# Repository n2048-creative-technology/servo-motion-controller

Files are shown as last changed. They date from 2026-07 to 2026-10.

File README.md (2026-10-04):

# Servo Motion Controller (XIAO ESP32C3 / ESP32S3)

A self-contained servo motion sequencer for a Seeed XIAO ESP32C3 **or**
ESP32S3, powered over USB-C. On boot it creates its own WiFi access point and
hosts a mobile-first web app (open the AP's IP in a phone browser, WLED-style)
for:

- Live manual aiming of a **pan/tilt head** — two servos, X (pan) on D10 and
  Y (tilt) on D3 — with a square XY trackpad whose extents follow each axis's
  own calibrated travel (270° out of the box, 180° if that's how you set that
  servo up).
- A relay output on pin **D7** for a light, switched by a toggle beside the
  trackpad.
- Parametric motion patterns — sine, square, triangle, sawtooth, trapezoid —
  each with adjustable period/amplitude/offset (and duty or rise/hold/fall
  ratios where relevant), looped continuously. **Each axis runs its own
  shape**, so the head can sweep in pan while nodding slowly in tilt.
- A **random** pattern: new target angles picked inside that axis's calibrated
  range at randomly-drawn intervals between two limits you set. Every move is
  speed-limited and eased in/out rather than jumped, so the servo tracks it
  smoothly instead of slamming from one position to the next. Set both axes to
  random and they share one schedule — the head looks at a whole new point
  each interval instead of twitching one axis at a time.
- Recording a manual performance (drag the trackpad) as a timestamped
  sequence, then saving and looping it back — both axes and the relay's state
  are captured and replayed together. Up to 6min40s per recording.
- An **autostart** setting: on every power-up/reset, the configured pattern
  or saved sequence starts looping automatically with no user interaction,
  because it's applied *before* WiFi/the web server come up.

## Hardware

Two supported boards, one firmware — pick the matching PlatformIO
environment (`seeed_xiao_esp32c3` or `seeed_xiao_esp32s3`) when building/flashing.

| | XIAO ESP32C3 | XIAO ESP32S3 |
|---|---|---|
| Power | USB-C (5V from host/charger) | USB-C (5V from host/charger) |
| Servo X (pan) | **pin D10 (GPIO10)** → servo signal wire | **pin D10 (GPIO9)** → servo signal wire |
| Servo Y (tilt) | **pin D3 (GPIO5)** → servo signal wire | **pin D3 (GPIO4)** → servo signal wire |
| Relay / light | **pin D7 (GPIO20)** → relay module IN | **pin D7 (GPIO44)** → relay module IN |
| Flash / RAM | 4MB / ~400KB SRAM | 8MB / ~512KB SRAM |

Both boards use the **same silkscreen-labeled pins** for all three outputs
— D10 (pan), D3 (tilt), D7 (relay) — so no wiring changes are needed when
switching boards, but note each is a *different underlying GPIO number* on
each chip (`SERVO_X_PIN` / `SERVO_Y_PIN` / `RELAY_PIN` in
`firmware/include/Config.h` are selected per-board via `ARDUINO_XIAO_ESP32S3`,
already handled for you).

| | |
|---|---|
| Servo power | **Do not power the servos from the XIAO's 3V3/5V pin.** Two servos that can move at once roughly double the peak draw; use a separate 5–6V supply sized for both, with its ground tied to the XIAO's GND. The relay module's coil side runs off that same supply, not the XIAO's 3V3. |
| Servo pulse range | Default 500–2500 µs, calibratable **per axis** in Settings (min/max pulse, min/max angle, center, invert) |

The default calibration assumes wide-range (~270°) servos, matching pulse
widths used in other projects in this workspace. Adjust min/max angle and
pulse width in the web UI's Settings tab to match each of your actual servos —
pan and tilt are calibrated separately, since a tilt servo usually has a
different mechanical range.

## Access point

- Default SSID: `ServoRig-XXXXXX` (last 3 MAC bytes, printed on the serial
  console at boot).
- Default password: `servo1234` (change it from Settings; leave it blank to
  run an open network — minimum 8 characters otherwise).
- Fixed AP IP: `192.168.4.1`. Visiting any other hostname while connected
  redirects there (best-effort captive portal — phone OS auto-popup
  detection isn't 100% reliable, so if it doesn't pop up, open
  `http://192.168.4.1/` manually).
- **There is no recovery WiFi network.** If you forget a custom AP password,
  the only way back in is `POST /api/settings/reset` — which you can't reach
  without a connection. In practice: flash a fresh build, or add a physical
  factory-reset trigger (e.g. a boot-time GPIO check) if you expect to need
  this in the field — not implemented here to keep scope minimal.
- Two arduino-esp32 gotchas that used to cause "correct password rejected"
  and "settings reset to factory defaults on every reflash" are worked
  around in `main.cpp`'s `setup()`: `WiFi.persistent(false)` stops a stale
  flash-cached AP config from fighting the one set at boot, and
  `WiFi.softAP()` is always called before `WiFi.softAPConfig()` (the reverse
  order silently drops the password even though `softAP()` reports success).
  Separately, AP SSID/password and Master/Node role/Node ID are stored under
  their own NVS key, independent of the versioned settings blob — so bumping
  `SETTINGS_VERSION` for an unrelated field (a new calibration option, a new
  pattern parameter) no longer wipes them back to factory defaults.

## Build & flash

Requires [PlatformIO](https://platformio.org/) (`pio` CLI).

**Pin the platform first**: `platform = espressif32` in `platformio.ini` is
unpinned, and the current release of it no longer compiles `NetworkLink.cpp`
(ESP-NOW callback signature change in arduino-esp32 3.x — see Known
limitations at the end). Use `platform = espressif32@6.10.0`, the version this
was developed and flashed with.

```bash
cd firmware
ENV=seeed_xiao_esp32c3   # or seeed_xiao_esp32s3
pio run -e $ENV              # compile firmware
pio run -e $ENV -t buildfs   # build the LittleFS web UI image

# with the board connected over USB-C:
pio run -e $ENV -t upload
pio run -e $ENV -t uploadfs
pio device monitor -e $ENV -b 115200
```

Both `firmware.bin` and the LittleFS image (`index.html`/`app.js`/`style.css`
in `firmware/data/`) must be flashed — `uploadfs` pushes the web UI, `upload`
pushes the firmware. Re-run `uploadfs` any time you edit files in `data/`.

**Native USB-CDC quirk on both XIAO boards**: `esptool`'s default
post-connect baud-rate change (and the RAM-stub handoff) failed consistently
over the native USB-CDC/JTAG port (`No serial data received` after "Stub
running..."). Fixed by pinning `upload_speed = 115200` and
`upload_flags = --no-stub` for both environments in `platformio.ini` (already
set) — `--no-stub` talks to the ROM bootloader directly instead of handing
off to a RAM stub, which is slower per-byte but reliable over this port. If
you flash from a different machine/OS and hit the same error, that's the
first thing to try; if your setup doesn't need it, it's harmless to leave in.

Verified end-to-end on real hardware, both boards: firmware and filesystem
flashed successfully to a connected XIAO ESP32C3 and a connected XIAO
ESP32S3, and each one's serial self-test log confirmed a clean boot —
settings loaded, both servos attached on the correct pins (GPIO10/GPIO5 on
the C3, GPIO9/GPIO4 on the S3 — silkscreen D10 and D3), the relay driven to
its off level on D7, LittleFS mounted, WiFi AP up
(`ServoRig-xxxxxx` @ `192.168.4.1`), web server started (~195KB free heap on
the C3, ~259KB on the S3, matching its larger SRAM). **Not verified**: the
web UI and API themselves, since this environment has no WiFi adapter to
join the AP and exercise `/api/*` or the WebSocket over the air — connect a
phone or laptop to the AP and walk through [docs/self-test.md](docs/self-test.md)'s
functional checklist (jog, pattern loop, record/save, autostart-after-reset)
to finish verification.

## Web app

Three tabs, reachable from the bottom nav:

- **Manual** — XY trackpad (live, ~25 Hz over WebSocket) with a Light toggle
  for the D7 relay beside it, + a pattern picker per axis with generated
  parameter fields and Start/Stop. The pad's extents and the pattern forms'
  angle fields both follow the per-axis calibration set in Settings. On a
  Master, two extra cards sit on top: **Target** (which Node(s) the controls
  drive) and **Play Sequence on Nodes** (make them loop a sequence saved on
  their own flash) — see *Multi-board Master/Node mode* below.

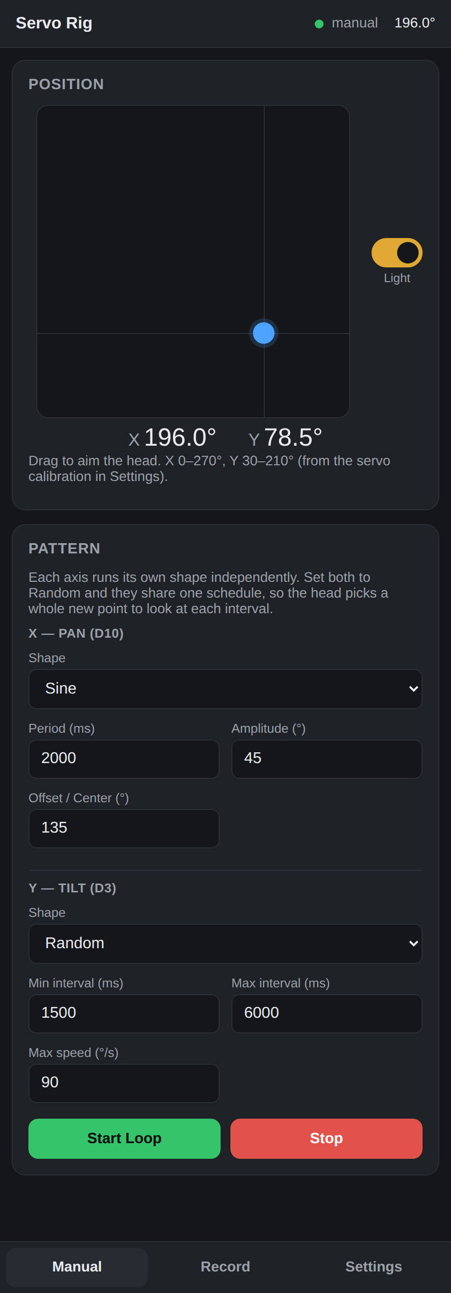
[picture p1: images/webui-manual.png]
Manual tab: XY trackpad with Light toggle, and a pattern shape per axis
  

- **Record** — start/stop recording (captures both servo axes *and* the
  relay's state at a fixed 20 Hz while you aim the head), live trace with one
  line per axis, **tap any saved recording to plot it** (with a playhead
  tracking it while it plays), save/discard,
  and play/stop the saved sequence on a loop. Playback drives the light from
  the recording just as it drives the servo. The trace plots both: the servo
  axes as two lines, and the light as a solid lane along the bottom (with a
  faint wash over the motion it happened during), so you can see at a glance
  which part of a take was lit. The same plot shows a *saved* recording when
  you tap its row in the list, downsampled by the board, with a thin white
  playhead following playback through it.

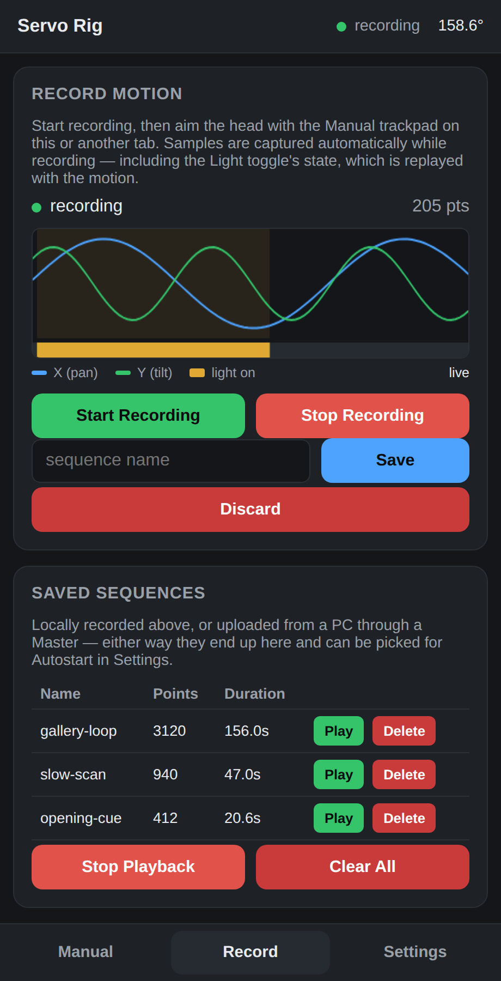
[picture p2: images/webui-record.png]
Record tab: live trace of both axes plus the light lane, and the saved-sequence list
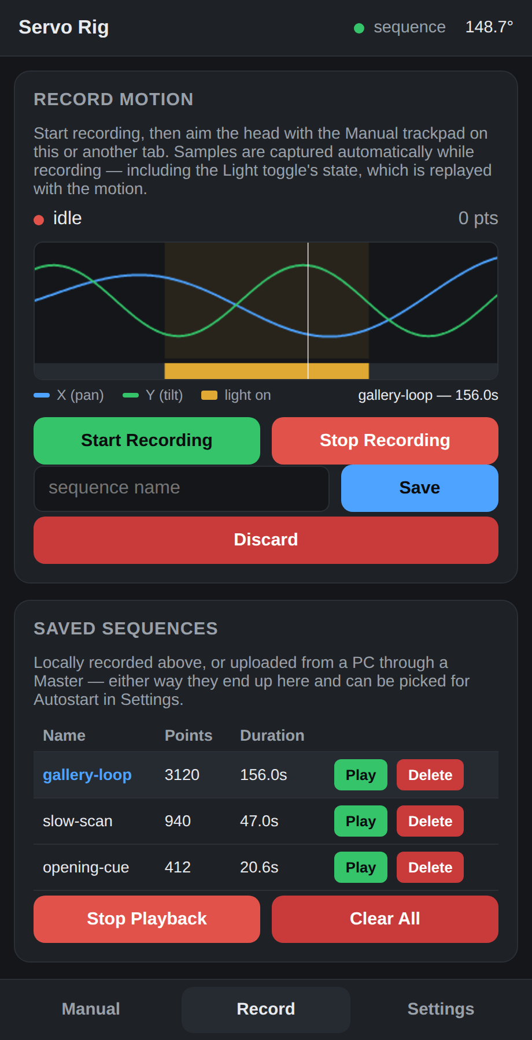
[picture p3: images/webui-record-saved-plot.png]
Record tab: a saved recording plotted with a playhead sweeping through it
   

  *Left: recording in progress — pan and tilt as two lines, the light as a
  lane along the bottom. Right: a saved recording tapped in the list, plotted
  with the white playhead tracking playback through it.*

- **Settings** — AP SSID/password, per-axis servo calibration (including
  **Invert direction**, for a servo mounted mirrored/reversed relative to its
  calibrated min/max angle), relay polarity (**Active low**, for the
  opto-isolated relay boards that switch closed on a low input), autostart
  enable/target (pattern or sequence) with its own parameter fields, and a
  factory-reset button.

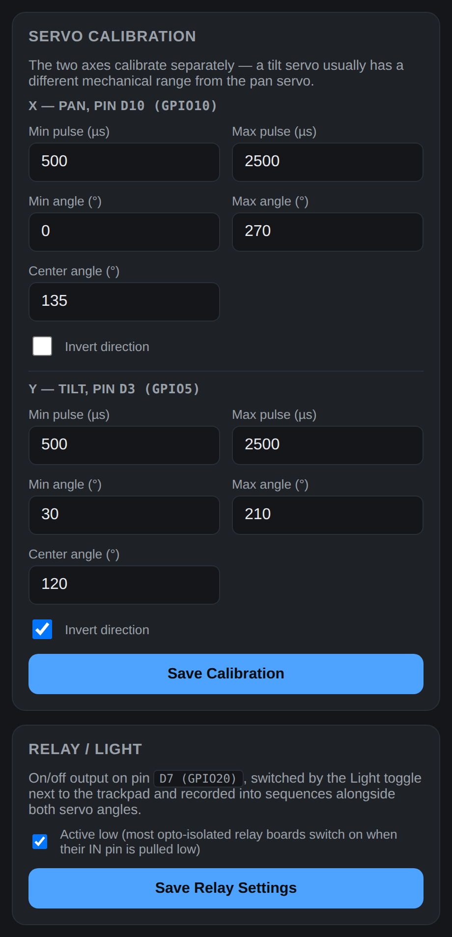
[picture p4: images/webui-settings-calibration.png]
Settings tab: per-axis servo calibration with invert checkboxes, and relay polarity
  

## REST / WebSocket API

See [docs/api.md](docs/api.md) for the full route table and payload shapes.
WebSocket `/ws` pushes `{"type":"status", mode, x, y, relay_on, ...}` at
~10 Hz and accepts `{"cmd":"jog","x":123.4,"y":90.0}` and
`{"cmd":"relay","on":true}` for low-latency manual control; on a Master it
also pushes `{"type":"play_result",...}` whenever a Node answers a play
request (`POST /api/network/play`). (`angle` is still
sent and accepted as a deprecated alias for `x`, so anything written against
the single-servo API keeps working.)

## Multi-board Master/Node mode (v2)

Every board still runs the same firmware and, by default, is exactly the
self-contained pan/tilt-plus-light rig described above (**Standalone** mode).
On top of that, a board can be switched (Settings → Network) into:

Settings → Network, all three modes:

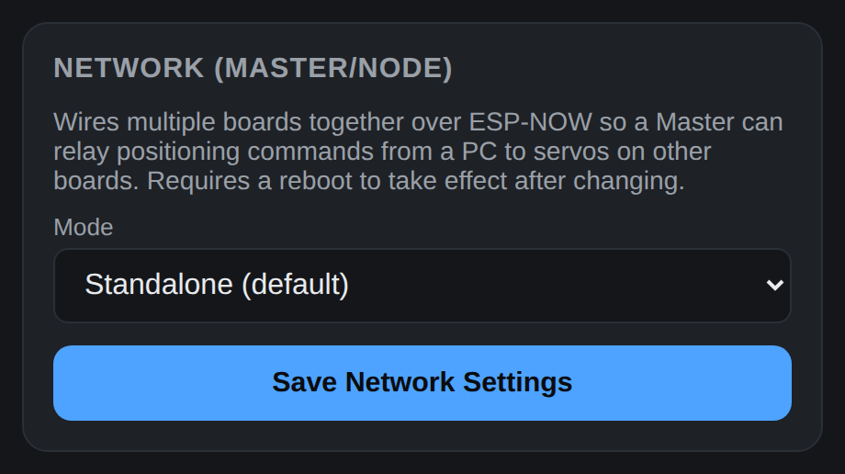
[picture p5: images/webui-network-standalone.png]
Network settings: Standalone mode
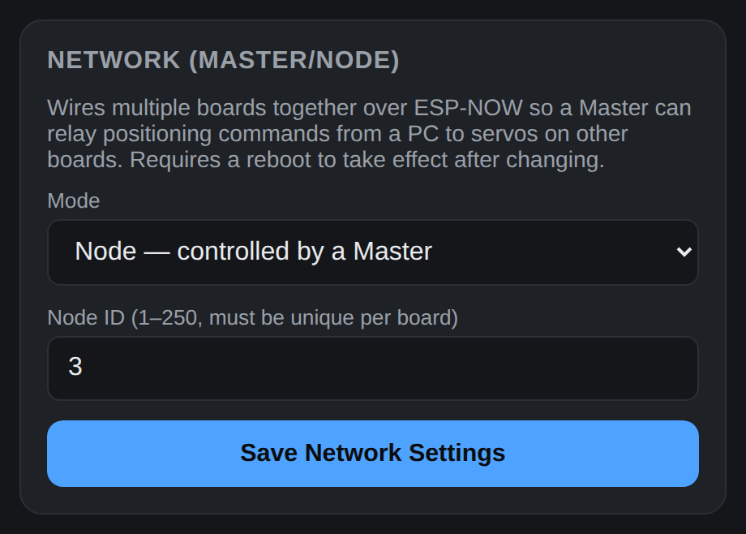
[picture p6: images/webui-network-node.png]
Network settings: Node mode with Node ID field
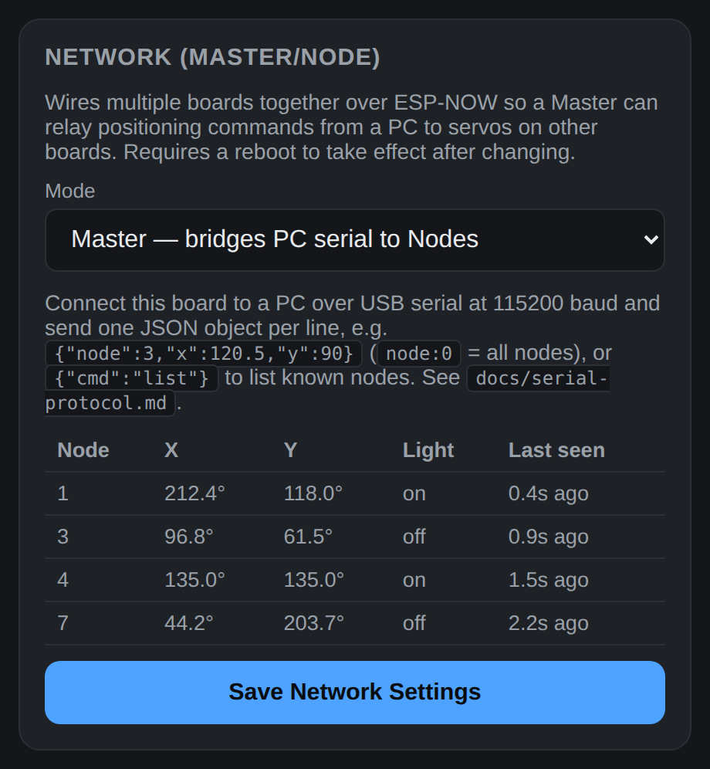
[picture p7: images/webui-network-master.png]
Network settings: Master mode with the known-nodes table showing each Node's pan, tilt and light
  

- **Node** — everything Standalone does, plus a **Node ID** (1–250) and an
  ESP-NOW listener: it accepts wireless positioning commands from a Master in
  addition to local jog/pattern/sequence control, and reports its status as
  `mode: "network"` while being driven that way. A local jog on the same
  board's web UI still takes over immediately (last command wins — there's no
  arbitration between the two sources).
- **Master** — a bridge, not a servo controller: connect it to a PC over
  USB-C and it relays newline-delimited JSON commands from that serial port
  to every Node in ESP-NOW range. See [docs/serial-protocol.md](docs/serial-protocol.md)
  for the wire format (`{"node":3,"x":120.5,"y":90.0}`, `{"cmd":"list"}`,
  etc.) and a `pyserial` example. A Master needs no servos attached.
  It can also tell Nodes to loop a sequence saved on their own flash
  (`{"cmd":"remote_play","node":3,"name":"dance1"}`, `node: 0` for all at
  once) and stop it again (`remote_stop`); the next ordinary move command
  takes a Node back to live control. Needs firmware 2.3.0+ on both ends.
  Both PC GUIs below have a **Play saved sequence on Node(s)** panel for this,
  and so does the Master's own web UI (2.4.0+, see next paragraph).

  A Master's **own web UI works too**: its Manual tab gets a "Target" card
  (Settings → Network → Master) listing known Nodes as checkboxes — select
  one, several, or check "All nodes" — and the existing trackpad / Light
  toggle / Pattern controls drive that selection over ESP-NOW instead of a
  local servo. Below it, **Play Sequence on Nodes** makes the selected
  Node(s) loop a sequence saved on their own flash (type the name — the
  Master's own saved names are suggested) and **Stop on Nodes** halts them;
  each Node's reply (playing / no such sequence / busy recording) is listed
  underneath. Handy
  for driving the rig by hand from a phone without any PC involved at all;
  the serial bridge above is for scripted/external control.

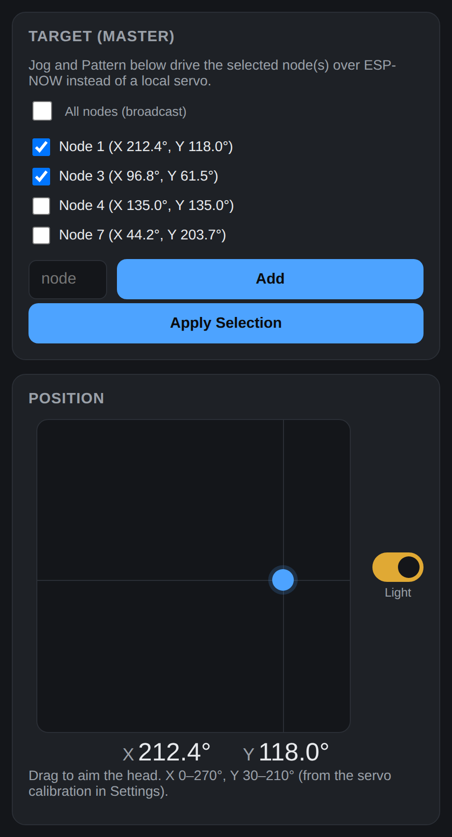
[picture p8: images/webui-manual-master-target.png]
Master's Manual tab: Target card listing known Nodes with their pan/tilt positions, above the trackpad
  

  For PC-driven control there's also [scripts-tools/master_gui.py](scripts-tools/master_gui.py),
  a small Tkinter app that connects to a Master's serial port, shows its known
  Nodes (pan, tilt, light state and age), and lets you aim a selection of them
  with an XY pad — light included — or broadcast to all, without writing any
  code:

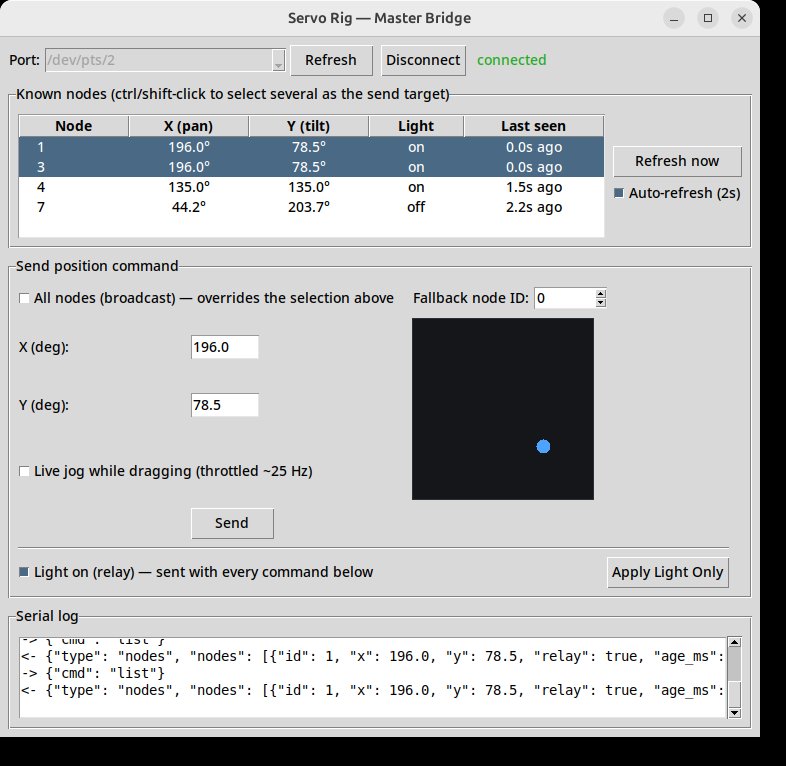
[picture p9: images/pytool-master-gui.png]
master_gui.py: known-nodes table with X/Y/Light columns, XY pad and light checkbox
  

  and [scripts-tools/joystick_master_gui.py](scripts-tools/joystick_master_gui.py),
  which links physical joysticks/gamepads to Nodes (with a "learn the axis"
  step that takes a whole stick as one pan/tilt pair, and buttons as a Node's
  light), streams live movement to them, and can record a performance to CSV
  (Node ID + pan + tilt + light per timestamp) for standalone replay without
  the controller — see [scripts-tools/README.md](scripts-tools/README.md).

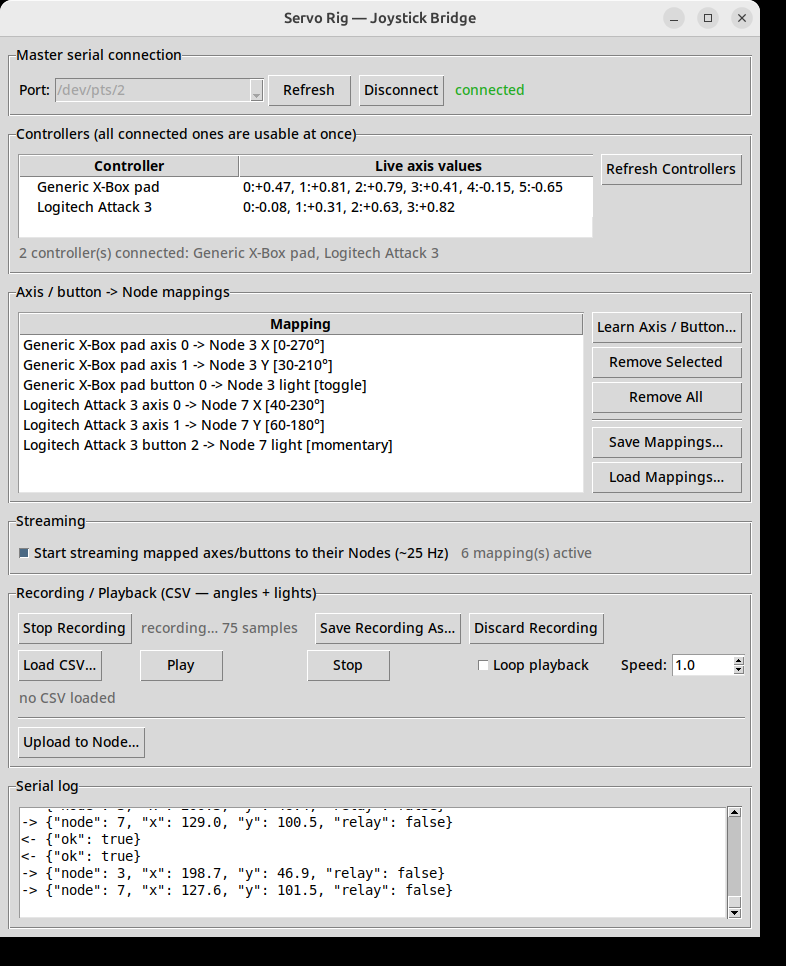
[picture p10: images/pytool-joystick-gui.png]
joystick_master_gui.py: two controllers detected, per-axis and per-button node mappings, streaming and recording
  

  **A performance doesn't have to stay tied to the PC.** `joystick_master_gui.py`'s
  **Upload to Node…** button takes a loaded CSV or a just-made recording,
  picks one Node ID present in it, and streams *only that Node's own column*
  through the Master to be saved on the Node's own flash under a name —
  other Nodes' data in the same recording is never sent to it. That Node's
  own Settings → Autostart can then pick any of its saved sequences (see the
  Record tab's list — locally recorded or uploaded, they show up the same
  way) to loop on every boot, completely standalone: no PC, no Master, no
  controller needed afterward. See
  [docs/serial-protocol.md](docs/serial-protocol.md)'s
  `remote_record_start`/`remote_record_stop` for the underlying protocol —
  it's implemented as a remotely-triggered recording, reusing the same
  RECORDING-mode capture path a Node's own web UI already uses.

How it works: Master and Nodes talk over **ESP-NOW** (direct ESP32-to-ESP32
radio, no router involved), broadcasting on the same fixed AP WiFi channel
every board already uses (`AP_WIFI_CHANNEL` in `firmware/include/Config.h`).
That's what makes it a drop-in addition to the existing self-contained-AP
design — no board has to join anyone else's network. The only setup step per
board is picking its mode and, for Nodes, a unique Node ID, from its own
Settings → Network tab; changes take effect after a reboot.

Known limitation: like the rest of this project's networking, there's no
encryption or pairing beyond the shared channel + Node ID — anyone else's
ESP-NOW traffic on the same channel with a colliding Node ID could also drive
a Node. Fine for a single installation's private RF environment; don't rely
on it where that's not true.

**Dropped packets self-heal.** A Node's radio/CPU is shared with whatever
else it's doing — e.g. a phone joining that same Node's AP to view its web
UI competes with ESP-NOW for airtime on the single RISC-V core. Rather than
a dropped command leaving a Node stuck, the Master re-sends the last angle
it sent to each target at least every 300ms even if unchanged, and each Node
independently re-applies its own last commanded angle to the servo at least
every 250ms — see `NET_CMD_RESEND_INTERVAL_MS`/`SERVO_REAPPLY_INTERVAL_MS` in
`firmware/include/Config.h`. Whichever command reached a Node *last* (local
jog, another app, a gamepad stream) always wins; if a gamepad moves faster
than packets can be delivered, intermediate positions may be skipped but the
Node reliably converges on the final position once movement stops.

That resend mechanism means more than one command for the same target is
often in flight, and a congested/degrading link (that same phone-on-the-AP
scenario) can deliver them **out of order** — without protection, a delayed
resend of an older angle arriving after a newer command would erratically
snap the servo backward. Every command now carries a per-boot session id
plus an increasing sequence number; a Node drops anything not newer than
what it already applied, so a late/stale packet is a no-op rather than a
step backward. This is the fix for the "servo moves erratically when the
network connection is flaky" symptom — see
[docs/serial-protocol.md](docs/serial-protocol.md) for the full picture.
Because the packet layout changed, **Master and every Node need matching
firmware** — a version mismatch makes them silently ignore each other
rather than misbehave.

## Storage

- Servo calibration, AP credentials, and autostart config live in NVS
  (`Preferences`, versioned blob — a magic/version mismatch falls back to
  factory defaults instead of crashing).
- Each recorded sequence lives in LittleFS at `/seq/<name>.bin` (12-byte
  header + up to 8000 points of `{t_ms, x*10, y*10, flags}`, i.e. up to
  6min40s at the 20 Hz capture rate — a board can hold several, named, picked
  for autostart or manual playback). It's only written on explicit **Save**,
  never per-sample, to avoid flash wear. A point is 12 bytes; when the Y axis
  was added the point count came down from 12000 so the fixed buffer stayed at
  the same 96KB rather than eating another 48KB of the C3's RAM. Sequences
  recorded by older firmware still load: their X and light tracks replay as
  before, and tilt is left alone rather than driven somewhere the recording
  never described.

## Known limitations / risks

- Single RISC-V core: the 50 Hz servo tick shares the core with
  AsyncWebServer/WebSocket event handling. Route handlers are kept
  non-blocking and JSON payloads small to avoid starving the tick.
- Captive-portal auto-popup varies by phone OS; the DNS catch-all + redirect
  is best-effort, `192.168.4.1` is the documented fallback.
- No STA/recovery network — see the access point section above.
- Flash is fairly full (72.3% of the app partition — 947,794 of 1,310,720
  bytes on the C3 as of v2.2.0) since `ESPAsyncWebServer` + `ArduinoJson` +
  `ESP32Servo` are meaningfully sized libraries on a 1.25MB app partition. If
  you add more features and hit the ceiling, look at a non-OTA partition
  table (`board_build.partitions`) to reclaim the unused second OTA app slot.
- **`platform = espressif32` is unpinned in `platformio.ini`, and the current
  release of it no longer builds this firmware.** arduino-esp32 3.x /
  ESP-IDF 5.x changed the ESP-NOW receive callback signature, so
  `NetworkLink.cpp`'s `esp_now_register_recv_cb(onRecvTrampoline)` fails to
  compile: `invalid conversion from 'void (*)(const uint8_t*, const uint8_t*,
  int)' to 'esp_now_recv_cb_t'` (the callback now takes a
  `const esp_now_recv_info*` first argument, carrying the sender MAC in
  `->src_addr`). This project was developed against **espressif32 6.10.0**,
  which is still installed here and builds cleanly. Until the trampoline is
  ported, pin it — `platform = espressif32@6.10.0` in `[env]` — or update the
  callback signature. Everything else in this repo (the web UI filesystem
  image included) builds on either.
- Master/Node mode is build-verified (`pio run` / `-t buildfs` both succeed)
  and boards on hand have been flashed and boot-confirmed over serial
  (settings v6, LittleFS OK, AP up), but the actual ESP-NOW link between a
  Master and a Node (a real serial or web-UI command moving a *remote*
  servo) hasn't been hands-on verified end-to-end from this environment —
  it has no WiFi adapter to join a board's AP and drive its web UI over the
  air. Set one board to Master / another to Node with a chosen Node ID and
  confirm it responds before relying on this in the field. AP SSID/password
  and Master/Node role/Node ID no longer reset on a `SETTINGS_VERSION` bump
  (they live under their own NVS key — see the Access point section above),
  so this no longer needs re-picking after an unrelated firmware update.
- The command-resend/reapply/ordering robustness mechanisms (see above) are
  build-verified and flashed to all 4 boards on hand, but reproducing the
  actual failure mode (a phone joined to a Node's AP while a gamepad drives
  it through the Master) needs real hardware, a real phone, and a real
  gamepad simultaneously, none of which this sandbox has all at once. Worth
  confirming in the field that a Node recovers on its own within
  ~300-550ms of the interference easing, without needing a reboot, and that
  it no longer snaps backward to a stale angle while doing so.
- Remote sequence upload (`remote_record_start`/`remote_record_stop`, and
  `joystick_master_gui.py`'s Upload to Node… button) is build-verified only —
  it bumped `NET_PACKET_VERSION` again (every board needs reflashing to stay
  in sync, same as the ordering fix above) and reuses well-exercised
  machinery (RECORDING mode, `resample_rows`), but the actual PC → Master →
  Node round trip, the on-Node save, and autostart picking it back up after
  a reboot haven't been exercised hands-on for the same no-WiFi-adapter
  reason as the rest of Master/Node mode. Worth a real end-to-end check:
  upload something, confirm it shows up in that Node's Settings → Autostart
  sequence picker, and that it survives a reboot.
- **How the screenshots above were made** (all of them show the current
  two-servo + relay build; they were re-captured for it):
  - Web UI: `firmware/data/` served by a local mock API — canned JSON in the
    exact shape `WebApi.cpp` returns, plus a `/ws` status stream at the
    firmware's own rate — driven in real headless Chromium. Real rendering,
    real app.js logic (the traces are genuinely drawn by the UI from status
    frames), but not the actual ESP32 backend or WiFi AP.
  - PC GUIs: both launched for real under a headless X server, connected to a
    stand-in Master on a pseudo-terminal that speaks
    [docs/serial-protocol.md](docs/serial-protocol.md) — so the node tables,
    the traffic in the serial logs and the recording counter are all the
    tools' own code doing real work. `joystick_master_gui.py`'s controllers
    are stubbed at the `pygame.joystick` boundary (no gamepad was plugged in
    here); everything below that — mapping load, streaming, recording — ran
    for real. Still not exercised end-to-end: a real Master board over USB
    with real Nodes on the other side.
  - Two things this pass caught and fixed in the tools themselves: the
    "connected" status label stayed red after connecting in both GUIs (the
    colour was computed but never applied), and `joystick_master_gui.py`'s
    default window was too short for its current control set, cutting off the
    serial log.

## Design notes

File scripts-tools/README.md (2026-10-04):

# scripts-tools

PC-side tools for this project. `master_gui.py` and `joystick_master_gui.py`
talk to a Master board over USB serial using the protocol in
[../docs/serial-protocol.md](../docs/serial-protocol.md) — `serial_link.py`
is their shared connection code, not a standalone tool. `upload_all.py` is a
build/deploy tool instead, driving PlatformIO directly rather than talking to
any board's firmware.

## `upload_all.py`

Flashes the latest firmware **and** LittleFS web UI to every connected board
in one go — the build-once-then-flash-in-parallel workflow used by hand
throughout this project's development, scripted. For each connected serial
port it probes the actual chip with `esptool` and matches it against
`firmware/platformio.ini`'s configured environments (via each environment's
installed board definition, not a hardcoded chip list — a new environment
added to `platformio.ini` needs no change here); anything that doesn't match
a configured environment — an unrelated serial device, or a board type this
project doesn't build for — is skipped with a clear reason instead of a
failed or garbled flash attempt.

```bash
python3 upload_all.py              # build + flash firmware and filesystem to every matched board
python3 upload_all.py --dry-run    # show what would be flashed, touch nothing
python3 upload_all.py --fw-only    # skip the filesystem image
python3 upload_all.py --fs-only    # skip the firmware binary
python3 upload_all.py --jobs 2     # limit how many boards flash at once (default 8)
```

Builds happen once per matched environment before any board is touched —
running multiple `pio run` invocations concurrently against the *same*
environment's build directory corrupts its SCons dependency cache (hit in
practice during this project's development); only the actual per-board
upload, which is safe to parallelize, fans out across boards. Verified
end-to-end against all 5 real boards on hand (1 Master + 4 Nodes, a mix of
XIAO ESP32C3 and ESP32S3): correctly identified each board's chip, matched
it to the right environment, and flashed firmware + filesystem to all 5
successfully.

## `master_gui.py`

A small Tkinter app that connects to a Master board over USB serial and
sends servo positioning commands to its Nodes — a GUI front-end for the
protocol in [../docs/serial-protocol.md](../docs/serial-protocol.md), for
when you'd rather drag a slider than write a script.

Setup:

```bash
python3 -m venv .venv && source .venv/bin/activate   # optional but recommended
pip install -r requirements.txt
python3 master_gui.py
```

Tkinter ships with most desktop Python installs. On Debian/Ubuntu, if `import
tkinter` fails, install it separately: `sudo apt install python3-tk`.

What it does:

- Lists and connects to serial ports (115200 baud, matching the Master).
- Polls the Master's known-node table (`{"cmd":"list"}`) every 2s and shows
  it in a table — pan, tilt, light state, and how long ago each Node last
  heartbeat-ed.
- Select one or more rows in that table (ctrl/shift-click) to target them,
  or check **All nodes** to broadcast; a fallback node-ID field covers
  targeting a Node that hasn't reported in yet.
- X/Y entry boxes and a square **XY pad** — click or drag to aim a node's
  pan/tilt head (left/right is pan, up is higher tilt, matching the web UI).
  A Send button fires one-shot moves, plus an optional "live jog" mode that
  streams the pad at ~25 Hz while dragging.
- A **Light on (relay)** checkbox for the D7 relay output, sent with every
  command, plus **Apply Light Only** to switch the target(s)' light without
  moving anything (it re-sends each Node's own last reported angle — the
  firmware carries relay state on move commands, so a light change always
  travels with an angle). The node table's **Light** column shows each Node's
  actual state, reported in its heartbeat, so it stays right no matter what
  switched it.
- **Play saved sequence on Node(s)**: type (or pick) a sequence name and hit
  **Play on Node(s)** to make the selected Node(s) loop that sequence from
  their own flash; **Stop** halts them. A play is repeated until each Node's
  `play_result` comes back (up to 4 tries), and the reply — playing, no such
  sequence, or busy recording — shows under the buttons. Any later move
  command to a Node takes it back under live control. Needs firmware 2.3.0+
  on the Master and the Nodes (see `remote_play` in the serial-protocol doc).
- A scrolling log of every line sent/received, for debugging.

A multi-node selection is a client-side fan-out — the GUI just sends one
`{"node": <id>, "x": ..., "y": ..., "relay": ...}` line per selected Node in
quick succession.
The wire protocol itself is unchanged; see the serial-protocol doc for the
full command/reply reference.

## `joystick_master_gui.py`

Drive Nodes from a physical joystick/gamepad instead of on-screen sliders,
using [pygame](https://www.pygame.org/) for controller input. Same setup as
above (`pip install -r requirements.txt` — this pulls in `pygame` too, then
`python3 joystick_master_gui.py`).

**Multiple controllers work at once** — plug in as many as you like (e.g. two
gamepads for two people, or a pile of specialized controllers), and freely mix
which one drives which Node: (controller 1, axis 2) → Node 3 and
(controller 2, axis 4) → Node 1 can coexist as two ordinary mappings. Each
mapping remembers its own controller by a stable per-device GUID (not by
plug-in order, which can change across reconnects), so it stays correctly
attached to the right physical device no matter what order things get
plugged in.

Workflow:

1. Connect to the Master's serial port (same as `master_gui.py`).
2. Connect your controller(s), then click **Refresh Controllers** — every
   detected controller is opened at once and listed with a live readout of
   its raw axis values, handy for telling axes apart. There's no "select a
   controller" step; all connected ones are available for mapping
   simultaneously.
3. Click **Learn Axis / Button…**, then move the stick, axis or button you
   want to link — on *any* connected controller — during the ~4 seconds the
   dialog is watching.

   **Move a whole stick** (both its axes) and it's learned as a pair: one
   dialog assigns both halves to one node's X (pan) and Y (tilt), with a
   Swap checkbox if your stick's axes come through the other way round, an
   Invert per axis (Y starts inverted, since pushing a stick down usually
   means tilting down), and a separate angle range for each. That's one step
   per pan/tilt head instead of two.

   Move a single axis and it's learned on its own — the form then asks which
   servo axis it drives. **Press a button** instead and it maps to a Node's
   light (a button press wins immediately and ends the watch early: axes
   idle with noise and drift, so a button going down is the unambiguous
   signal of intent). It watches every axis and button of every controller
   at once and, for an axis, picks whichever moved the most, identifying
   both the controller and the axis automatically, shows you its observed
   raw range, and asks you to assign a **Node ID** — pick one from the dropdown of Nodes the Master has
   actually heard a heartbeat from (auto-refreshed every 2s in the
   background; hit the dialog's own Refresh if one just came online), or
   type an ID directly for a Node that hasn't reported in yet — and an
   **angle range** (defaults to 0–270°, the firmware's default servo
   calibration — adjust to match the target servo's actual calibrated range
   from its own Settings tab). An **Invert** checkbox flips direction
   without needing to redo the range. Repeat per axis you want to use, on
   whichever controller it's on; one axis can also be linked to more than
   one Node if you add it again. **Save Mappings…** writes the whole mapping
   list (each with its own controller GUID + name, axis index, calibrated
   raw range, Node ID, angle range, invert) to a JSON file; **Load
   Mappings…** restores them later without re-learning. A mapping whose
   controller isn't currently connected shows `[controller not connected]`
   in the list and is skipped by streaming/recording until you plug it back
   in and click Refresh Controllers — it isn't lost, and reattaches
   automatically once that controller (matched by GUID, or by name as a
   fallback for files saved by an older version of this tool) is back.
   **Remove All** clears every mapping at once (with a confirmation prompt)
   instead of selecting them one by one.

   A **button** mapping asks only for a Node ID and a behaviour:

   - **Toggle** (default) — each press flips that Node's light, like a wall
     switch. What you want for a light left on across a take.
   - **Momentary** — the light follows the button: on while held, off on
     release. For flashing/strobing by hand.

   Each Node's light is switched independently: the Master tracks relay
   state per target, so a button on Node 3 never disturbs Node 5's light.
   One controller can carry a mix of axis and button mappings, and both
   kinds are saved to (and loaded from) the same mapping JSON file —
   mapping files written before button mappings existed still load as
   axis-only, unchanged.
4. Check **Stream mapped axes to their Nodes** to start sending — every
   mapped axis, across all connected controllers, is recalculated ~25 Hz and
   only resent when it moves more than ~0.2°, to avoid flooding the link
   while idle. Each node gets **one command per tick carrying both of its
   axes and its light**, never one per axis — the firmware needs them
   together so a head can't act on half a move. A channel you haven't mapped
   for a node (tilt but no pan, a light-only node) is filled with wherever
   that node already is, so it holds rather than snapping.
5. **Start Recording** captures every mapped Node's computed pan, tilt *and*
   light state (not the raw axis/button — the physical controller's identity
   is irrelevant on playback) at the same ~25 Hz, timestamped from recording
   start. **Save Recording As…** writes it to CSV: a `t_ms` column plus
   `node_<id>_x`, `node_<id>_y` and `node_<id>_light` columns for whichever
   channels that Node actually has, e.g.:

   ```csv
   t_ms,node_3_x,node_3_y,node_3_light,node_7_x
   0,135.0,90.0,0,200.0
   40,138.2,92.5,1,201.0
   80,141.0,95.0,1,202.0
   ```

   A Node only gets the columns it has data for, so a pan-only mapping
   doesn't write a column of blanks for tilt. Older CSVs still load and
   play: a bare `node_<id>` column is read as that Node's pan (the servo
   those recordings were made with), tilt is left alone, and a missing
   `_light` column simply means the light stays off.

6. **Load CSV…** + **Play** replays a recording by sending `{"node":
   <id>, "x": ..., "y": ..., "relay": ...}` — no controller needed at all, so
   a captured performance, lighting included, can be replayed standalone.
   Lights are held (stepped) between samples rather than interpolated, so a
   relay never chatters at the sample rate. **Loop** repeats it; **Stop**
   cancels mid-playback. **Speed** (0.1–2.0, default 1.0) doesn't just scale
   the delay between the original rows — pressing Play resamples the whole
   recording onto a fresh ~25 Hz grid at that speed (the CSV file itself is
   untouched): below 1.0 it interpolates *extra* in-between points so slow
   motion stays smooth instead of getting choppy from stretched-out gaps;
   above 1.0 it interpolates *down* to ~25 Hz instead of bursting every
   original row as fast as possible. Either way playback always lands
   exactly on the final recorded position.
7. **Upload to Node…** pushes a recording onto a Node's own flash instead of
   just replaying it live: pick a source (the loaded CSV or your last live
   recording), a Node ID present in it (or check **Upload to all Nodes
   present in source** to push every Node's own column to its Node at
   once), and a name. Each Node only ever receives its own columns — its pan,
   tilt and light tracks, whichever of them the recording has — never
   another Node's data, streamed through the Master at real-time pace (via
   `remote_record_start`/`remote_record_stop`, see
   [../docs/serial-protocol.md](../docs/serial-protocol.md)). Because the
   light rides on the same move commands the Node is capturing, the sequence
   saved on its flash replays the lighting along with the motion — including
   on autostart, with no PC connected. A Node with only a light track (a
   button mapped but no axis) uploads too: it holds its current position
   while its light is recorded. Multiple
   Nodes' uploads run concurrently rather than queued one after another —
   each Node's point stream overlaps almost completely with the others —
   with only a small (~150ms per Node) stagger to their start, so their
   remote_record_start/stop control packets and SEQ_ACK replies don't all
   land in the same instant and collide (real hardware testing without this
   staggering showed every Node's ack getting lost when four uploads landed
   at once). The status line/log track each Node's own progress plus a
   combined summary once every Node in the batch has finished. Each Node
   saves its sequence and can then loop it on every
   boot via its own Settings → Autostart, completely standalone — no PC,
   Master, or controller needed afterward. Long recordings (over
   6min40s, a Node's own capacity now that each recorded point carries both
   axes) are truncated with a warning per Node.
   The start request is sent redundantly (a lost one is otherwise invisible
   — the Node still moves on every point of the stream that follows
   regardless of whether it actually started recording) and a failed/lost
   stop-and-save confirmation is retried once automatically. Re-uploading a
   name that already exists on a Node overwrites it. Check **Clear Node's
   saved recordings before uploading** to have each target Node delete every
   sequence it's currently holding (`remote_clear`, see
   [../docs/serial-protocol.md](../docs/serial-protocol.md)) right before its
   own upload starts — a clean slate, e.g. to keep a Node's flash from
   accumulating a pile of one-off names over many test uploads. Before
   streaming anything, each Node's upload also asks it how much flash space
   it has free (`space_query`) and estimates the recording's on-disk size
   from its duration — if the Node's own reply shows there isn't enough
   room, that Node's upload is aborted immediately with a clear error
   instead of streaming for the full duration only to fail at the very end;
   a Node that doesn't answer within ~800ms (a dropped packet, not
   necessarily a real problem) just gets uploaded to anyway. A failure's log
   line and status text explain *why* where possible — a Node that captured
   no movement at all most often means either its start request never
   arrived or **it lost power and reset partway through the transfer**:
   recordings with frequent large, fast swings can brown out a Node from the
   servo's own current draw and reset it mid-upload — this is a power-supply
   characteristic, not a firmware bug (see
   [../docs/serial-protocol.md](../docs/serial-protocol.md) for how this was
   isolated). If uploads fail specifically on your highest-motion
   recordings, that's the first thing to check.
8. **Discard Recording** clears the in-memory recording buffer (the one
   **Save Recording As…**/**Upload to Node…** would use) without writing it
   anywhere — a confirmation prompt guards against losing an unsaved take.
   To clear what's already saved *on a Node's own flash*, either check
   **Clear Node's saved recordings before uploading** in the Upload dialog,
   or use the **Clear All** button in that Node's own web UI (Record tab).
9. **Play saved sequence on Node(s)** plays what step 7 put on the Nodes,
   *on the Nodes themselves* — no PC streaming involved, so it keeps running
   with the PC unplugged. Enter node ids (`3,5`; `0` = all) and a sequence
   name (names you've uploaded this session are in the dropdown), then
   **Play on Node(s)** / **Stop**. It stops the PC-side CSV **Play** first,
   since that stream's next row would take the Nodes straight back. Same
   panel and retry behaviour as in `master_gui.py`; moving a mapped stick
   for a Node also takes it back under live control.

The axis-mapping math, CSV round-trip (X/Y/light columns plus both older
formats), button toggle/momentary edge handling, mapping-file compatibility,
stick-pair detection, and upload data-extraction/resampling logic are all
unit-tested, both GUIs' widget trees are built and rendered as a smoke test, and the window itself has been launched and visually confirmed
on a real display with two real controllers connected simultaneously (an
Xbox pad and a Logitech joystick) — but the Upload to Node… flow's actual
PC → Master → Node round trip hasn't been exercised against real hardware in
this sandbox (no WiFi adapter here to complete that loop), and neither has a
real relay switching from a real gamepad button. Try both before relying on
them for a show.

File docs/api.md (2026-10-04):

# REST / WebSocket API

Base URL: `http://192.168.4.1` while connected to the device's AP.

## REST routes

| Method | Route | Body | Response / notes |
|---|---|---|---|
| GET | `/api/status` | — | `{mode, x, y, angle, relay_on, uptime_ms, free_heap, firmware_version, recording:{active,points}, sequence:{present,name,points,duration_ms,playing,position_ms}}` — `x`/`y` are the two servo axes (`angle` is a deprecated alias for `x`); `sequence.position_ms` is how far into the loop playback has got, for a playhead |
| GET | `/api/patterns` | — | `[{type, label, params: "comma,separated,keys"}]` — drives the UI's generated param forms |
| POST | `/api/pattern/start` | `{x:{type, period_ms, …}, y:{…}}` | mode → `pattern`, loops until stopped. Either axis may be omitted to leave it as-is; a flat body with no `x`/`y` is applied to X |
| POST | `/api/pattern/stop` | — | mode → `manual`, holds last angle |
| POST | `/api/manual/jog` | `{x_deg?, y_deg?}` | REST fallback for manual moves; prefer WS `jog` for latency. An omitted axis holds its position; `angle_deg` is still accepted as X |
| POST | `/api/relay` | `{on}` | switches the relay/light on D7; doesn't change `mode` (see below) |
| GET | `/api/network/targets` | — | `{broadcast_all, node_ids:[...]}` — Master only: which Node(s) `manual/jog`, WS `jog`, and `pattern/start` currently drive |
| POST | `/api/network/targets` | `{broadcast_all, node_ids:[...]}` | Master only: retarget jog/pattern output — broadcast to all Nodes, or an explicit id list (client-side fan-out, one ESP-NOW CMD per id); ephemeral, resets to broadcast-all on reboot |
| POST | `/api/network/play` | `{node, name}` | Master only: make Node `node` (`0` = all) loop sequence `name` saved on **its own** flash — the web side of serial `remote_play`. `{"ok":true}` means the ESP-NOW send went out; the Node's answer arrives as a WS `play_result`. Not retried by the firmware — the web UI repeats it until that ack. `400 send_failed` on a non-Master |
| POST | `/api/network/stop` | `{node}` | Master only: stop that Node's (`0` = all) sequence playback, holding position — serial `remote_stop`. No ack; send it a few times |
| POST | `/api/record/start` | — | clears the in-RAM recording buffer, mode → `recording` |
| POST | `/api/record/stop` | — | mode → `manual`; buffer is kept until save/discard |
| POST | `/api/record/save` | `{name}` | writes the buffer to `/seq/<name>.bin` (sanitized to `[A-Za-z0-9_-]`, ≤23 chars) |
| POST | `/api/record/discard` | — | clears the buffer without saving |
| GET | `/api/sequences` | — | `[{name, points, duration_ms}, ...]` — every sequence saved on this board, local or uploaded via a Master |
| GET | `/api/sequence/data?name=…&points=…` | — | `{name, duration_ms, has_y, points:[[t_ms,x,y,light], ...]}` — a downsampled view of one saved sequence, for plotting it. `points` caps at 300 (the plot is only ~600px wide); reading never disturbs whatever is currently playing |
| POST | `/api/sequence/play` | `{name}` | loads and plays that sequence on loop; mode → `sequence` |
| POST | `/api/sequence/stop` | — | mode → `manual` |
| POST | `/api/sequence/delete` | `{name}` | removes that sequence file; clears it as "active" first if it was playing |
| POST | `/api/sequences/clear` | — | removes every saved sequence on this board; `{ok:true, removed:N}` |
| GET | `/api/settings` | — | `{ap:{ssid,has_password}, servo:{x:{pin,min_us,max_us,min_angle,max_angle,center_angle,invert}, y:{…}}, relay:{pin,active_low,on}, autostart:{enabled,target,pattern:{x:{…},y:{…}},sequence_name}, network:{mode,node_id}}` — password is never echoed back |
| POST | `/api/settings` | any subset of the GET shape (`ap.password` only if changing it) | persists to NVS; servo calibration changes take effect immediately, `network.*` changes need a reboot (see `/api/reboot`) |
| POST | `/api/settings/reset` | — | restores factory defaults (only recovery path if AP credentials are forgotten) |
| POST | `/api/reboot` | — | applies pending AP credential / network-mode changes via `ESP.restart()` |
| GET | `/api/network/nodes` | — | `{nodes:[{id,x,y,relay,age_ms}, ...]}` — a Master's in-RAM table of Nodes it has heard an ESP-NOW heartbeat from (`x`/`y`/`relay` are each Node's actual state, however it was set); empty list on Standalone/Node boards |

`mode` is one of `idle`, `manual`, `recording`, `pattern`, `sequence`, `network`
(`network` = last moved by a wireless command from a Master, Node boards only).

## Two axes

A node drives a pan/tilt head: **X (pan) on D10** and **Y (tilt) on D3**. The
two calibrate independently (`servo.x` / `servo.y`), run their own pattern
each, and are both captured into recordings.

Both axes always travel together in one command — one `jog`, one CMD packet,
one recorded point. Splitting them would let a node act on half a move,
visibly dog-legging its way to a diagonal and recording that dog-leg if a
capture is running.

`/api/sequence/data` reports `has_y: false` for a sequence recorded before
there was a tilt axis — its `y` column is padding, not data, and shouldn't be
plotted as a flat line at zero.

Sequences recorded before this firmware had a Y axis still load and play:
their X and light tracks replay as before, and the tilt axis is left where it
is rather than being driven somewhere the recording never described.

`relay.active_low` inverts the pin level the "on" state drives, for relay
boards that switch closed when their IN pin is pulled low. It changes only the
electrical level: `relay_on`, `POST /api/relay`, and what a recording stores
all mean the same logical on/off either way. `relay.pin` is read-only
(compiled in per board — GPIO20 on the C3, GPIO44 on the S3, silkscreen D7 on
both); `relay.on` is the live state and is ignored on POST — switch it with
`POST /api/relay` instead.

`servo.<axis>.invert` flips which physical end of the pulse range a given
angle drives (for a servo mounted mirrored/reversed relative to how min/max
angle were calibrated) — it doesn't change what an angle *means* to the rest of
the API: jog/pattern/sequence/network commands, recordings, and `GET
/api/status`'s `angle` are unaffected, only the resulting pulse direction is.

`network.mode` is one of `standalone` (default), `node`, `master` — see
[serial-protocol.md](serial-protocol.md) for the Master's PC-facing protocol
and the ESP-NOW design behind Master/Node mode.

When `autostart.target` is `"sequence"`, `autostart.sequence_name` picks
*which* saved sequence (from `GET /api/sequences`) loops on boot — a board
can hold several (locally recorded, or remotely uploaded by a Master; see
serial-protocol.md's `remote_record_start`/`remote_record_stop`), not just
one fixed recording like early versions of this firmware.

On a **Master** board the Light toggle behaves like the trackpad: it
switches the relay on whichever Node(s) `/api/network/targets` selects, not
the Master's own D7 pin. Relay state is tracked per target, so a Node's light
is only changed by a command actually addressed to it.

On a **Master** board, `/api/manual/jog`, the WS `jog` command, and
`/api/pattern/*` don't drive a local servo at all — they drive whichever
Node(s) `/api/network/targets` currently selects, over ESP-NOW. `GET
/api/status`'s `angle`/`mode` then reflect the last commanded network angle,
not a physical servo position.

## WebSocket `/ws`

- **Client → server**: `{"cmd":"jog","x":123.4,"y":90.0}` — immediate manual
  move, same effect as `POST /api/manual/jog` but lower latency. Either axis
  may be omitted (it holds); `angle` is still read as X.
- **Client → server**: `{"cmd":"relay","on":true}` — same effect as
  `POST /api/relay`.
- **Server → client**, Master only, whenever a Node answers a play request
  (from the web UI or serial): `{"type":"play_result","node":3,"name":"dance1","ok":true}`,
  plus `"reason"` when `ok` is false — same shape as the serial `play_result` line.
- **Server → client**, ~10 Hz: `{"type":"status", "mode":..., "x":..., "y":..., "relay_on":..., "uptime_ms":..., "free_heap":..., "recording":{...}, "sequence":{...}}` — same shape as `GET /api/status`.

## Pattern parameter keys

| Key | Applies to | Meaning |
|---|---|---|
| `period_ms` | all | one full cycle duration |
| `amplitude_deg` | all | peak deviation from `offset_deg` |
| `offset_deg` | all | center angle the pattern oscillates around |
| `duty_pct` | square | % of the period spent at the high value |
| `rise_pct` / `hold_pct` / `fall_pct` | trapezoid | % of the period for each ramp segment (remainder is held low) |
| `interval_min_ms` / `interval_max_ms` | random | bounds of the randomly-drawn interval from one move to the next |
| `max_speed_dps` | random | speed ceiling for each move, in degrees per second (5–400) |

Angle produced = `offset_deg + amplitude_deg * shape(phase)`, where `shape`
is a normalized waveform in `[-1, 1]` — see
`firmware/src/PatternEngine.cpp`.

### `random`

The one shape that isn't a waveform, and the one that ignores `period_ms` /
`amplitude_deg` / `offset_deg` entirely. Each cycle it picks a new target
uniformly inside that axis's **calibrated travel** (`servo.min_angle` …
`servo.max_angle`, so a servo configured for 180° never gets sent past 180°),
then waits a fresh interval drawn uniformly from `[interval_min_ms,
interval_max_ms]` before the next one.

Getting there is deliberately not a jump. Each move is eased with a smoothstep
profile — zero velocity at both ends — stretched over however long it takes to
keep peak speed at or below `max_speed_dps`, so what reaches the servo is a
ramp it can track instead of a step that would slam the gear train and spike
the current draw. Two consequences worth knowing:

- The interval covers the **whole cycle** (move + hold), not just the pause.
  If a long move wouldn't fit in the drawn interval, the interval is extended
  so the move always completes plus a short settle — a large range with a low
  speed cap therefore moves less often than the interval bounds alone suggest.
- Changing servo calibration re-ranges a running random pattern immediately;
  no restart needed.
- Set **both** axes to `random` and they share one schedule: the head picks a
  whole new (X, Y) point each interval and travels there as a single eased
  move, with the duration set by whichever axis needs longer so neither
  breaks its own speed cap. Set only one to `random` and it runs on its own
  schedule alongside whatever waveform the other axis is doing.

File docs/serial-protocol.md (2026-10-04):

# Master serial protocol

A board in **Master** mode (Settings → Network) bridges a PC connected over
USB to every **Node** board in ESP-NOW range. It reads newline-delimited JSON
from `Serial` and turns positioning commands into ESP-NOW broadcasts; it
never drives a locally-attached servo itself.

- Port: the board's USB-CDC serial port (e.g. `/dev/ttyACM0` on Linux).
- Baud: `115200`.
- Framing: one JSON object per line, terminated by `\n`. `\r` is tolerated
  and stripped.

## Commands (PC → Master)

**Move a node**
```json
{"node": 3, "x": 120.5, "y": 90.0}
```
- `node`: target Node's id (`0`–`250`). `0` broadcasts to every Node.
- `x`: pan angle (D10) in degrees, clamped by that Node's own X calibration.
- `y`: tilt angle (D3) in degrees, clamped by that Node's own Y calibration.
- `angle`: accepted as a synonym for `x`, so scripts written for the
  single-servo firmware keep working.

**An axis you leave out holds its last commanded position** rather than
snapping to a default, so a tool that only drives pan never disturbs tilt.
Both axes travel in one packet: splitting them would let a Node act on half a
move, dog-legging its way to a diagonal — and recording that dog-leg if a
capture is running.
- `relay` *(optional, boolean)*: also switch that Node's relay/light output
  on D7. **Omit it to leave the light alone** — the Master remembers the last
  state sent to each target and re-sends that, so a tool that knows nothing
  about the relay can't switch one off by accident.

Relay state is tracked **per target**, so switching Node 3's light never
disturbs Node 5's — one button per Node on a gamepad works as you'd expect
(see `joystick_master_gui.py`). The one thing to watch: `node: 0` (broadcast)
is its own target entry, so a broadcast command carries *its* relay state to
every Node at once. Mix broadcast and per-node commands with that in mind —
if you're controlling lights individually, address Nodes individually.

The relay state travels on the move command rather than in a packet of its
own so it inherits the angle's resend and ordering guarantees — and so a Node
recording a Master-driven sequence captures the light exactly in step with
the motion, which a separate best-effort packet couldn't promise.

To switch a light without moving anything, re-send that Node's current angle
(from `{"cmd":"list"}`, below) with the new `relay` value.

**List known nodes**
```json
{"cmd": "list"}
```
Returns the Master's in-RAM table of Nodes it has heard a heartbeat from
(nodes broadcast one every ~1s while running — see `NET_HELLO_INTERVAL_MS` in
`firmware/include/Config.h`). Entries aren't actively expired; treat a large
`age_ms` as "probably offline".

**Upload a sequence to a Node** — remotely triggers a recording on that Node
(same effect as its own web UI's Record tab), so it ends up saved on the
Node's own flash under a name, playable standalone via that Node's Settings
→ Autostart with no PC/Master/controller involved afterward:
```json
{"cmd": "remote_record_start", "node": 3}
```
Then stream ordinary move commands (`{"node":3,"x":...,"y":...}`, above) at a
steady real-time pace — the Node is now in RECORDING mode, so every command
that reaches it both moves its servo *and* gets captured. When done:
```json
{"cmd": "remote_record_stop", "node": 3, "name": "dance1"}
```
`name` is sanitized to `[A-Za-z0-9_-]`, truncated to 23 characters. The Node
saves whatever it captured as `/seq/<name>.bin` — overwriting any existing
file of that name — and reports back asynchronously (see `upload_result`
below) — this can take a moment, since it travels Node → Master over ESP-NOW
after the save completes. A Node's recording buffer caps at `MAX_SEQ_POINTS ×
RECORD_INTERVAL_MS` (6min40s by default — 8000 points at 50ms); don't stream
longer than that or the excess is silently dropped. `scripts-tools/joystick_master_gui.py`'s
"Upload to Node…" button implements this whole flow, including only ever
sending one Node's own column from a multi-node recording (see its README).

**Clear a Node's saved recordings** — deletes every sequence file on that
Node, same effect as its own web UI's "Clear All" button in the Record tab:
```json
{"cmd": "remote_clear", "node": 3}
```
Unlike the upload commands above, this has no delivery confirmation (no
`upload_result`-style reply) — it's a one-shot housekeeping step, so the reply
`{"ok":true}` only means the Master queued the ESP-NOW send locally, not that
the Node actually received and finished it. `joystick_master_gui.py`'s Upload
dialog has a "Clear Node's saved recordings before uploading" checkbox that
sends this and waits a short settle time before starting the upload.

**Check a Node's free space** — an upload preflight check, asking how much
LittleFS space a Node has left before streaming a recording to it:
```json
{"cmd": "space_query", "node": 3}
```
Replies asynchronously (see `space_reply` below), same fire-and-forget
delivery characteristics as `remote_clear` — no guarantee it arrives or that
a reply comes back. `joystick_master_gui.py`'s Upload dialog sends this
automatically before every upload, estimates the recording's on-disk size
from its duration, and aborts that Node's upload with a clear error if the
reply shows insufficient space; if no reply arrives within ~800ms it uploads
anyway rather than blocking on an unreliable link.

**Play a sequence saved on a Node** — makes that Node loop one of its own
saved sequences (recorded on it, or uploaded as above), same effect as its own
web UI's Record tab ▸ Play:
```json
{"cmd": "remote_play", "node": 3, "name": "dance1"}
```
- `node`: `0` tells every Node to play its own copy of `name` at once — a
  Node without one reports `ok:false` (below) and stays where it is.
- The Master **stops re-sending its last position** to that Node (see
  *Robustness against dropped packets* below), since that resend would
  otherwise pull it straight back out of playback. Because the broadcast
  target's resend reaches every Node, its entry is dropped too; for `node: 0`
  every entry is. A Node whose entry was dropped just holds its position.
- If the Master's **own** web UI is driving that Node (a trackpad jog, a
  pattern, or a sequence playing on the Master — all of which keep writing
  positions to the selected Node(s)), the Master goes idle too, or its next
  write would pull the Node straight back. This only happens when the
  Master's Target selection reaches that Node. (Firmware 2.4.0+.)
- **Any ordinary move command to that Node afterwards takes it back to live
  control** — no stop needed — and the Master resumes re-sending as before.
- Repeating the request is harmless: a Node already looping that sequence
  keeps going instead of restarting from zero. That makes retrying safe —
  this is a single ESP-NOW packet with no delivery guarantee, so send it two
  or three times, or until `play_result` arrives. To restart a sequence from
  the top, `remote_stop` it first.
- Ordered like a move command (same `sessionId`/`seq`, see *Ordering* below):
  a move still in flight when the play request lands can't knock the Node
  back out of playback, and a play request delayed past newer moves is
  dropped rather than hijacking a Node you're already driving live again.
- Every Node starts when the packet reaches it — within a few ms of each
  other — and then keeps time on its own clock, so Nodes playing in parallel
  stay together for minutes but aren't locked to each other.

**Stop a Node's sequence playback** — it halts and holds its current
position (same as its web UI's Stop). `node: 0` stops every Node:
```json
{"cmd": "remote_stop", "node": 3}
```
Same resend/ordering handling as `remote_play`. Fire-and-forget: no
`play_result` comes back for a stop.

Both commands need **firmware 2.3.0 or newer on the Master and the Node**.
`master_gui.py` and `joystick_master_gui.py` both have a **Play saved
sequence on Node(s)** panel that sends them (with the retries above), and a
2.4.0 Master's own web UI has the same thing on its Manual tab.
The packet layout didn't change, so `NET_PACKET_VERSION` didn't either: a
Node still on older firmware keeps working with a 2.3.0 Master for
everything else and simply ignores these two commands (no `play_result`
arrives).

## Replies (Master → PC)

- Move command: `{"ok":true}` or `{"ok":false,"error":"..."}`
- `list`: `{"type":"nodes","nodes":[{"id":3,"x":120.5,"y":90.0,"relay":true,"age_ms":840}, ...]}`
  — `x`, `y` and `relay` are that Node's *actual* state, reported in its own
  heartbeat, so they reflect the head however it was moved or switched (a
  Master command, the Node's own web UI, or its sequence playback).
- `remote_record_start`/`remote_record_stop`: `{"ok":true}` once the ESP-NOW
  send itself succeeded — *not* confirmation the Node actually saved
  anything, that's the separate asynchronous `upload_result` below.
- `upload_result` (asynchronous, arrives whenever the Node's own SEQ_ACK
  makes it back — could be well after the `remote_record_stop` reply):
  `{"type":"upload_result","node":3,"name":"dance1","ok":true,"points":842}`.
  `ok:false` means the Node received the stop request but failed to save;
  a `"reason"` string is included explaining why (no movement was ever
  captured — most often because the start request never arrived, or the
  Node lost power/reset partway through; an invalid name; or a write
  failure, e.g. out of space). No reply at all after a few seconds means the
  stop request itself likely didn't arrive — resend it.
- `remote_play`/`remote_stop`: `{"ok":true}` once the ESP-NOW send
  succeeded — not confirmation the Node started; that's `play_result`.
- `play_result` (asynchronous, one per Node that received a `remote_play`):
  `{"type":"play_result","node":3,"name":"dance1","ok":true}`. On
  `ok:false` a `"reason"` says why: no saved sequence by that name on the
  Node, or the Node is busy recording (loading would wipe the capture).
  Nothing back after a moment means the request was probably lost — resend.
- `space_reply` (asynchronous, reply to `space_query`):
  `{"type":"space_reply","node":3,"free_bytes":48200}`.
- Malformed line: `{"ok":false,"error":"bad_json"}`

Every reply is also one line, `\n`-terminated.

## Robustness against dropped packets

ESP-NOW has no delivery guarantee, and a Node's radio/CPU is shared with
whatever else it's doing — e.g. a phone joining that Node's own AP to view
its web UI competes for airtime/CPU with ESP-NOW on the same single core.
Two mechanisms make this self-healing instead of silently getting stuck:

- **Master**: remembers the last angle sent to each target (a specific Node
  id, or the broadcast target) and re-sends it at least every
  `NET_CMD_RESEND_INTERVAL_MS` (300 ms by default), even if nothing changed.
  A command that gets dropped in transit is corrected by the next periodic
  resend without needing a new movement to trigger it.
- **Node**: independently of receiving anything new, re-applies its last
  commanded angle to the servo at least every `SERVO_REAPPLY_INTERVAL_MS`
  (250 ms by default).

Net effect: whichever command — local jog, another app's command, or a
gamepad's stream — reached a Node *last* always wins and keeps winning, and
if the gamepad moves faster than packets can be delivered, intermediate
positions may be skipped but the Node reliably converges on the final
position once movement stops (see `firmware/include/Config.h` for both
constants).

### Ordering: a resend can't move the servo backward

The periodic resend above means more than one in-flight CMD packet for the
same target is now normal, not exceptional. Under a degraded/congested link
(the same phone-joins-the-AP scenario), packets can be delayed enough to
**arrive out of order** — without protection, a resend of an *older* angle
that gets delayed past a *newer* command would erratically yank the servo
back after it had already moved on.

Every CMD packet carries a per-boot `sessionId` (randomized when a Master's
ESP-NOW comes up) and a `seq` that increments on every send, resends
included. A Node tracks the highest `(sessionId, seq)` it's applied and
silently drops anything not newer — so a delayed/stale packet is a no-op,
never a step backward. A changed `sessionId` (the Master rebooted) always
wins, so a Node doesn't get stuck ignoring a Master that came back with its
counter reset to 0. Non-finite angles (a corrupted payload) are dropped the
same way, as cheap insurance against ever computing a garbage pulse width.

This is why **Master and every Node must run matching firmware** — a
`NET_PACKET_VERSION` mismatch (bumped whenever the packet layout changes,
as it did for this ordering fix) makes them silently ignore each other
rather than misinterpret each other's bytes.

A Node can hold **6min40s** of recording (8000 points at 50ms). That came
down from 10 minutes when each point gained its Y axis: the point grew 8 → 12
bytes, and the count was cut to keep the fixed buffer at the same 96KB rather
than spend another 48KB of the C3's RAM. See `MAX_SEQ_POINTS` in
`firmware/include/Config.h`.

### A Node can reset mid-upload on fast/large movements — this is a power issue, not a protocol one

Uploading a recording with frequent large, rapid swings (e.g. repeatedly
slewing close to a servo's full 0–270° range within a couple of ticks) can
brown out a Node and reset it mid-transfer, purely from the servo's own
current draw spiking faster than its power supply can source — confirmed by
reproducing it with real recorded joystick data, then ruling out every
software explanation: the *identical* recording succeeds after a fresh
reboot, and a gentle low-amplitude recording of the same duration succeeds
reliably on the exact same board and firmware every time, while the
high-motion one fails consistently. ESP-NOW/servo software can't distinguish
this from ordinary packet loss — it just sees the Node go silent and its
retry/timeout logic (and the `NoPointsCaptured` reason above) kick in the
same as any other dropped connection. If uploads fail specifically on
high-motion recordings: give the servo(s) their own adequately-sized supply
rather than sharing the ESP32's own rail, add bulk capacitance near the
servo, or — if that's not practical mid-show — favor recordings with gentler
transitions.

## Requirements for this to work

- Every board that should talk to each other (Master + all its Nodes) must
  share the same fixed AP WiFi channel — `AP_WIFI_CHANNEL` in
  `firmware/include/Config.h` (`1` by default, not currently exposed in the
  UI). ESP-NOW only reaches peers on the same channel; if you ever change
  that constant, rebuild and reflash every board in the group.
- Each Node needs a unique Node ID (1–250) assigned in its own Settings →
  Network tab. Two Nodes sharing an ID will both react to commands addressed
  to that ID.
- The Master needs no Node ID and no servo attached — it's a pure bridge.
- **Every board — Master and all Nodes — needs matching firmware.** Each CMD
  and HELLO packet carries a `NET_PACKET_VERSION`; a board running an older
  or newer build than the rest silently drops (and, since this version,
  logs) every packet from/to it rather than misinterpreting the bytes. A
  Node that "disappears" from the Master's known-node table despite being
  powered on and in range — while everything else works — usually means it
  missed the last firmware update round. Check the Master's serial console
  for `[NET] ignoring packet with protocol version...` and reflash whatever
  it names.

## Example: `pyserial`

```python
import json
import serial

port = serial.Serial("/dev/ttyACM0", 115200, timeout=1)

def move(node_id: int, x: float, y: float) -> dict:
    port.write((json.dumps({"node": node_id, "x": x, "y": y}) + "\n").encode())
    return json.loads(port.readline())

def list_nodes() -> dict:
    port.write(b'{"cmd":"list"}\n')
    return json.loads(port.readline())

print(move(3, 120.5))
print(list_nodes())
```

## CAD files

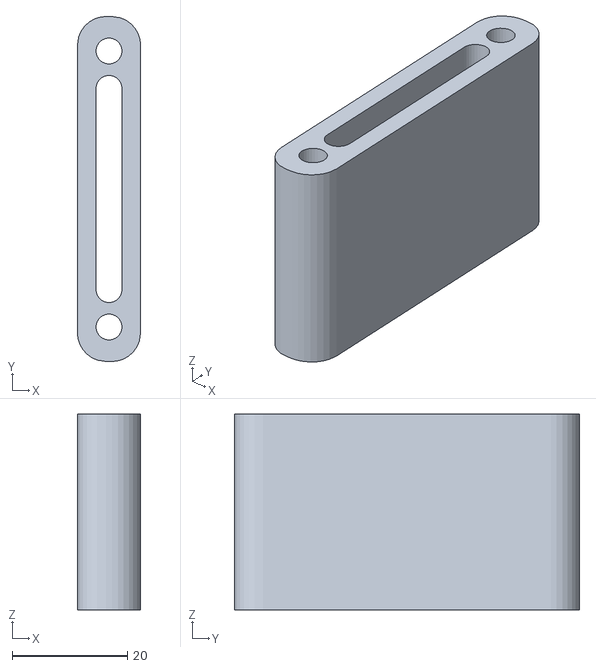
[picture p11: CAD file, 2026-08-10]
3dmodels/test-holder-stand.stl
11.0 x 60.0 x 34.0

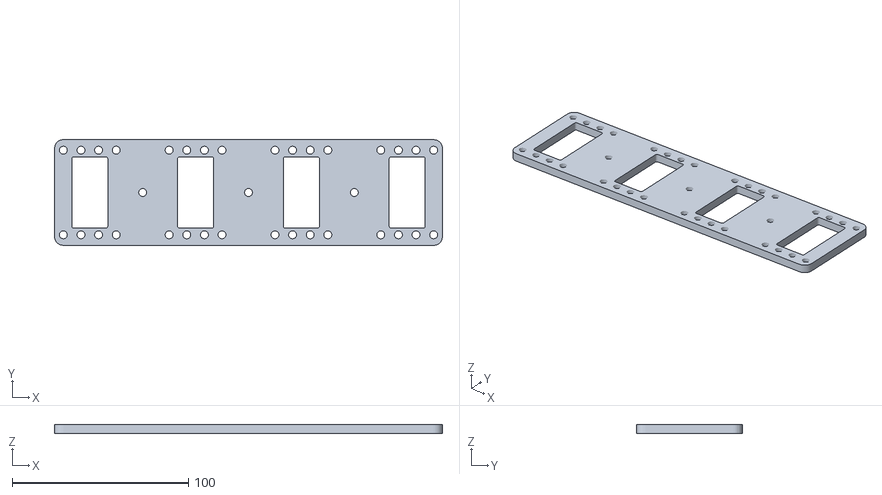
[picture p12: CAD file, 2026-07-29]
3dmodels/test-holder.stl
220.0 x 60.0 x 5.00

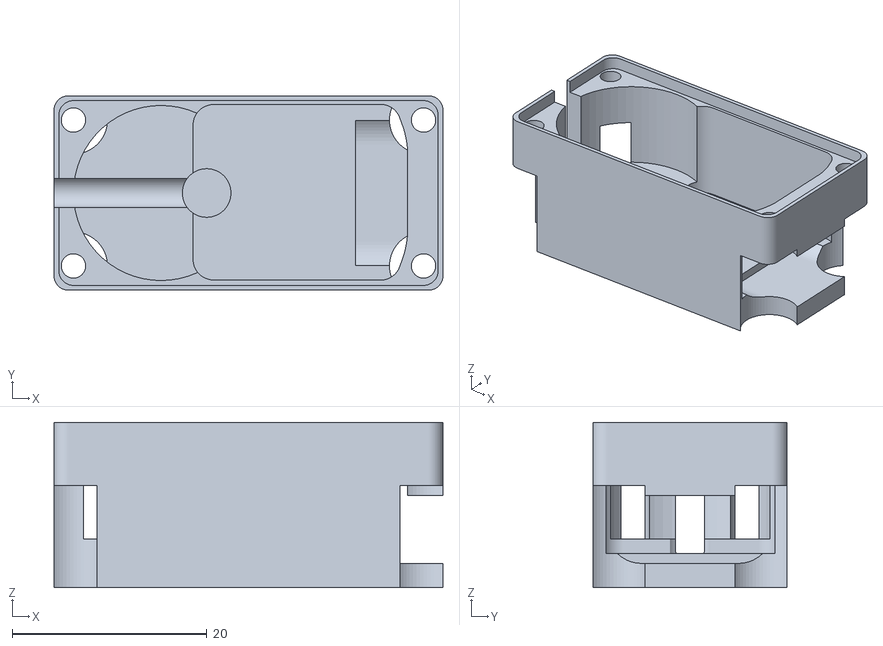
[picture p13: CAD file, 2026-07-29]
3dmodels/muizei-25kg-case-hack-for-seeedstudio-esp32c3.stl
40.0 x 20.0 x 17.0

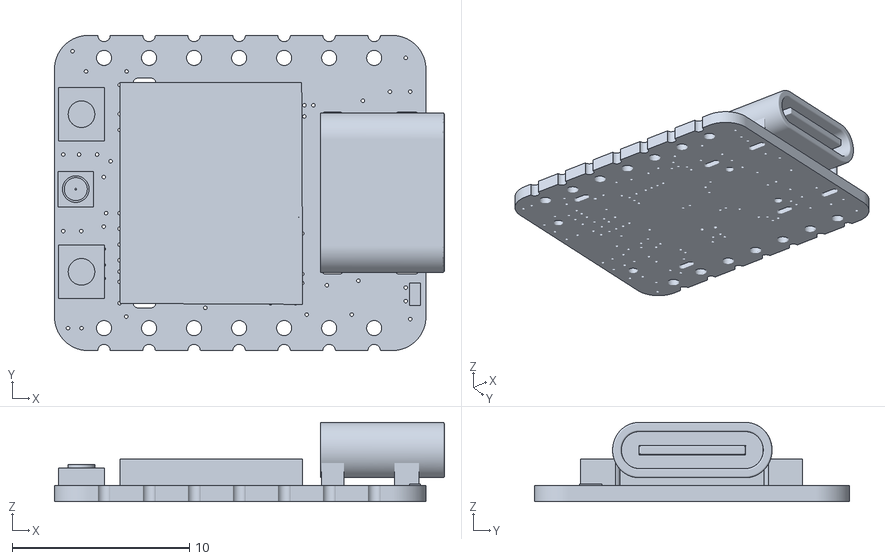
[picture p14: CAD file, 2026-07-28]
3dmodels/Seeed Studio XIAO ESP32C3.stl
22.0 x 17.8 x 4.47

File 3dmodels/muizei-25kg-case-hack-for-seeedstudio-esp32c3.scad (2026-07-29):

$fn=60;

module xiao(){
translate([-74,-17.7,2.16]) import("/home/mauricio/Documents/PlatformIO/Projects/servo-motion-controller/3dmodels/Seeed Studio XIAO ESP32C3.stl");
}


//%translate([5,0,1]) xiao();

difference(){
    linear_extrude(17) offset(1.5) offset(-1.5) square([40,20],center=true);
  
    translate([5,0,3.5]) linear_extrude(16) offset(.2) projection(cut=true) translate([0,0,-3]) hull() xiao();
    
    
    translate([36,15]/2) cylinder(d=2.5,h=100,center=true);
    translate([-36,15]/2) cylinder(d=2.5,h=100,center=true);
    translate([36,-15]/2) cylinder(d=2.5,h=100,center=true);
    translate([-36,-15]/2) cylinder(d=2.5,h=100,center=true);
    
    translate([0,0,17-1.5]) linear_extrude(5) offset(1.5) offset(-1.5) square([40-1,20-1],center=true);
    
    translate([11,0,6]) rotate([0,90])linear_extrude(10) hull(){
        translate([0,5]) circle(d=7);
        translate([0,-5]) circle(d=7);
    }
    
   translate([-4,0,4]) rotate([0,-90]) hull(){
        cylinder(d=3,h=30);
        translate([20,0]) cylinder(d=3,h=30);
    }
    
    translate([-4.3,0,2]) cylinder(d=5,h=10);
    
    translate([-9,0,5]) cylinder(d=18,h=20);
    
    
    translate([36,15]/2) cylinder(d=7,h=21,center=true);
    translate([-36,15]/2) cylinder(d=7,h=21,center=true);
    translate([36,-15]/2) cylinder(d=7,h=21,center=true);
    translate([-36,-15]/2) cylinder(d=7,h=21,center=true);
    
    
}

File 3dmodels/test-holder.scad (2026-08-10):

$fn=30;

servos = 4;

linear_extrude(5)
difference(){
    translate([-20,-30]) offset(5) offset(-5) square([60*servos-20,60]);

for(i=[0:servos-1]) translate([i*60,0]) {
offset(1) offset(-1) offset(0.2) square([20,40],center=true);
    
    translate([10,48]/2) circle(d=4.5);
    translate([10,-48]/2) circle(d=4.5);
    translate([-10,48]/2) circle(d=4.5);
    translate([-10,-48]/2) circle(d=4.5);


    translate([30,48]/2) circle(d=4.5);
    translate([30,-48]/2) circle(d=4.5);
    translate([-30,48]/2) circle(d=4.5);
    translate([-30,-48]/2) circle(d=4.5);
    
    translate([30,0]) circle(d=4.5);
   
}
 
}



!linear_extrude(34){
difference(){
    offset(5) offset(-5) square([11,60], center=true);
    translate([0,48]/2) circle(d=4.5);
    translate([0,-48]/2) circle(d=4.5);
    hull(){
    translate([0,35]/2) circle(d=4.5);
    translate([0,-35]/2) circle(d=4.5);
    }
}
}

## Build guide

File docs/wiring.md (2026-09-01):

# Wiring

```
                 +-------------------------+
   USB-C  ------>| XIAO ESP32C3 / ESP32S3  |
                 |                         |
                 |  D10           o--------+----> Servo X / pan  signal
                 |  D3            o--------+----> Servo Y / tilt signal
                 |  D7            o--------+----> Relay module IN
                 |  GND           o--------+----> Servo GND (brown/black) ----+
                 |                         |      + relay module GND         |
                 +-------------------------+                                 |
                                                                              |
                 +-------------------------+                                 |
   5-6V supply-->| Servo power rail        |                                 |
                 |  V+  o------------------+----> Servo V+ (red)             |
                 |  GND o--------------------------------------------------->+
                 +-------------------------+
```

- **Signals**: XIAO pin **D10** → the pan (X) servo, **D3** → the tilt (Y)
  servo, on either board. These are the same silkscreen-labeled pins on both,
  but different GPIOs underneath — `SERVO_X_PIN` and `SERVO_Y_PIN` in
  `firmware/include/Config.h` select the right ones per board automatically
  (compiled in per-environment, nothing to configure). Each axis's pin is
  also shown next to its own calibration block in the Settings tab.
- **Power**: run the servos from a separate 5–6V supply sized for their stall
  current, not from the XIAO's own 3V3/5V rail. **Two servos roughly double
  the peak draw**, and both can move at once — a supply that just coped with
  one pan servo is the first thing to suspect if a Node starts resetting
  during fast moves (see docs/serial-protocol.md's brownout section). Tie the servo supply's GND to the XIAO's GND
  (common ground) — without this the PWM signal has no reference and the
  servo will behave erratically or not move at all.
- **Relay**: XIAO pin **D7** → the relay module's IN/signal pin, plus a shared
  GND. Power the module's coil side from its own 5V supply (the servo supply
  works), not the XIAO's 3V3 — a relay coil pulls tens of mA and switching it
  couples noise back into the rail the servo signal references. If your module
  switches on when IN goes *low* (most opto-isolated boards do), tick
  **Active low** in Settings → Relay / Light; nothing needs reflashing.
- **XIAO power**: USB-C only, as specified. Neither the C3 nor the S3 draws
  meaningfully within USB power budgets; it's the servos and the relay coil
  that need their own supply.

## Pin choice notes

| Board | D10 = | Why |
|---|---|---|
| XIAO ESP32C3 | GPIO10 | General-purpose pin, no strapping-pin conflicts at boot (unlike GPIO2/8/9 on this chip, which affect boot mode selection). |
| XIAO ESP32S3 | GPIO9 | General-purpose pin on this chip — the S3's boot-strapping pins are GPIO0/3/45/46, none of which GPIO9 shares. Confirmed booting cleanly on real hardware with the servo pin on GPIO9. |

| Board | D3 (tilt) = | Why |
|---|---|---|
| XIAO ESP32C3 | GPIO5 | General-purpose pin; not one of the C3's strapping pins (GPIO2/8/9) and not used by anything else in this firmware. |
| XIAO ESP32S3 | GPIO4 | General-purpose pin; not one of the S3's strapping pins (GPIO0/3/45/46). |

Both servos share LEDC timer 0 — they run at the same 50Hz, which is what a
shared timer supports, and each still gets its own channel (the C3 has 6).

| Board | D7 = | Why |
|---|---|---|
| XIAO ESP32C3 | GPIO20 | UART0's RX pin, and free to use as a plain output here: both board definitions build with `ARDUINO_USB_CDC_ON_BOOT=1`, so `Serial` — the boot log and the Master's PC bridge alike — runs over native USB and never touches UART0. Not a strapping pin. |
| XIAO ESP32S3 | GPIO44 | Same story on the S3: UART0 RX, unused because `Serial` is USB CDC. Not one of the S3's strapping pins (GPIO0/3/45/46). |

The one thing to know about D7: because it *is* UART0 RX, wiring a relay there
rules out ever driving these boards over the hardware UART instead of USB. If
you need that, move `RELAY_PIN` in `firmware/include/Config.h` to a free pin
(D1, D2, D4 and D5 are unused by this firmware — D3 is the tilt servo) and
reflash. The relay is driven low
before the pin is switched to an output at boot, so an active-low module
doesn't get a momentary "on" pulse during startup.

If you need to move a servo to a different pin, change `SERVO_X_PIN` or
`SERVO_Y_PIN` in `firmware/include/Config.h` (both are already conditional per
board via `ARDUINO_XIAO_ESP32S3` — keep that in mind if you add a pin
override) and reflash. Double-check your target chip's specific strapping-pin list in
Espressif's technical reference manual before picking a low-numbered GPIO —
it varies by chip, not just by board.

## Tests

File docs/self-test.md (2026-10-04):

# Boot self-test (serial monitor)

Connect at 115200 baud (`pio device monitor -e seeed_xiao_esp32c3 -b 115200`)
right after a power-cycle or reset. A healthy boot prints all of the
following `[SELFTEST]` lines within a couple of seconds, with no `[ERROR]`
lines and free heap comfortably above ~40KB:

```
[SELFTEST] booting servo-motion-controller
[SELFTEST] firmware version=2.4.0
[SELFTEST] settings loaded (version=6, autostart=0)
[SELFTEST] servos attached X=pin10 500-2500us, Y=pin5 500-2500us
[SELFTEST] relay pin=20 active_high, starting off
[SELFTEST] littlefs mount OK
[SELFTEST] sequences stored: 0
[SELFTEST] wifi AP up ssid=ServoRig-A1B2C3 ip=192.168.4.1
[NET] esp-now ready, role=standalone node_id=7
[SELFTEST] autostart disabled
[SELFTEST] webserver started, ws clients=0
[SELFTEST] free heap=185344 bytes, network mode=0 node_id=7
```

`network mode` is `0` standalone / `1` node / `2` master, matching
`OperatingMode` in `firmware/include/Config.h`. `node_id` starts from a value
derived from the board's own MAC (so two fresh boards usually differ rather
than colliding) until you set one in Settings → Network — yours won't be 7.

On a **Master** board there is no `autostart` line at all — autostart only
makes sense with servos attached locally, and a Master drives Nodes instead.

The two servo pins in `servos attached` are the compiled-in ones for that
board: `X=pin10, Y=pin5` on the C3, `X=pin9, Y=pin4` on the S3 — silkscreen
D10 and D3 either way.

A board that once ran the v1 single-file firmware prints one extra line the
first time it boots this version, as its old recording is migrated into the
named-sequence directory:

```
[SEQ] migrated legacy sequence file to /seq/local.bin
```

On a board with no saved sequences you'll also see one or two benign lines
from the LittleFS wrapper around the `sequences stored` line:

```
[   379][E][vfs_api.cpp:105] open(): /littlefs/seq/local.bin does not exist, no permits for creation
[   381][E][vfs_api.cpp:105] open(): /littlefs/sequence.bin does not exist, no permits for creation
```

That's `LittleFS.exists()` — called to decide whether there's a v1 recording
to migrate — logging at ESP-IDF's error level merely because the files aren't
there. Expected and harmless, not a real error.

What each line confirms:

| Line | Confirms |
|---|---|
| `firmware version` | Which build is actually on the board — compare it against the web UI's Settings → About, which reports the *filesystem* image's version; a mismatch means only one of `upload`/`uploadfs` took |
| `settings loaded` | NVS read succeeded (or factory defaults were written on first boot). `version` is `SETTINGS_VERSION`, currently 6 |
| `servos attached` | LEDC timer + pulse ranges initialized for **both** axes: pan on D10, tilt on D3, each with its own calibrated pulse range |
| `relay pin=...` | Relay output driven to its off level on D7 (GPIO20 on the C3, GPIO44 on the S3); `active_low` reflects the Settings → Relay / Light polarity |
| `littlefs mount OK` | Filesystem partition is readable (formats itself on first-ever boot) |
| `sequences stored: N` | How many saved sequences are in `/seq` — locally recorded or uploaded from a PC through a Master |
| `esp-now ready` | Radio link initialized for the configured role (printed by `NetworkLink`, not the self-test block) |
| `autostart ...` | Whether a pattern/sequence started looping automatically, and which mode. Absent on a Master |
| `wifi AP up` | SoftAP came up with the configured SSID at the fixed IP |
| `webserver started` | HTTP/WebSocket server and captive-portal DNS are live |
| `free heap` | Sanity check — if this trends down across boots/reflashes, investigate for leaks |

If `littlefs mount OK` fails, the web UI won't be served — re-run
`pio run -t uploadfs`. If `wifi AP up` fails, double check the configured
SSID isn't empty and the password (if set) is empty or ≥8 characters.

## Functional checks once connected to the AP

1. Open `http://192.168.4.1/` — the Manual tab should load with live X and Y
   readouts that update as you drag the trackpad.
2. Pick a pattern per axis (e.g. Sine on X, Triangle on Y), hit **Start
   Loop** — both readouts should oscillate on their own, independently.
3. Switch to Record, hit **Start Recording**, aim the head with the Manual
   trackpad for a few seconds, **Stop Recording**, give it a name and
   **Save** — it should appear in the Saved Sequences list, and in Settings →
   Autostart's sequence picker.
4. Enable Autostart with a target, power-cycle the board, and confirm the
   head starts moving on its own — both axes, and the light if the sequence
   captured one — before you reconnect to the AP.
5. Flip the **Light** toggle beside the trackpad — the relay should click and
   stay switched. If it's on when the toggle is off (and vice versa), tick
   **Active low** in Settings → Relay / Light.
6. Drag around the **XY trackpad** — pan should follow left/right and tilt
   up/down, both staying inside their own calibrated limits.
7. Pick the **Random** pattern for *both* axes, set a short interval range,
   hit **Start Loop** — the head should look at a new point at irregular
   intervals, easing into and out of each move rather than snapping, with
   both axes arriving together. Nothing should ever take either axis past
   its Min/Max angle; lower **Max speed** if the moves look faster than the
   servos can comfortably track.
8. Record while moving both axes and toggling the Light partway through,
   save, then play it back — pan, tilt and light should all replay together.
9. Tap the saved recording's row in the list — the plot above should switch
   from the live trace to that recording, and while it plays a thin white
   playhead should sweep across it in time with the head. (A recording made
   before this firmware had a tilt axis plots its pan trace only, and says so
   next to the legend.)

These functional steps require real hardware and have not been run in this
environment — only the firmware and filesystem-image builds were verified.

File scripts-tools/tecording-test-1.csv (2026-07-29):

t_ms | node_1 | node_2 | node_3 | node_4
7 | 135.0 | 135.0 | 135.0 | 135.0
48 | 135.0 | 135.0 | 135.0 | 135.0
89 | 135.0 | 135.0 | 135.0 | 135.0
129 | 135.0 | 135.0 | 135.0 | 135.0
170 | 135.0 | 135.0 | 135.0 | 135.0
210 | 135.0 | 135.0 | 135.0 | 135.0
251 | 135.0 | 135.0 | 135.0 | 135.0
291 | 135.0 | 135.0 | 135.0 | 135.0
333 | 135.0 | 135.0 | 135.0 | 135.0
373 | 135.0 | 135.0 | 135.0 | 135.0
414 | 135.0 | 135.0 | 135.0 | 135.0
455 | 135.0 | 135.0 | 135.0 | 135.0
496 | 135.0 | 135.0 | 135.0 | 135.0
537 | 135.0 | 135.0 | 135.0 | 135.0
578 | 135.0 | 135.0 | 135.0 | 135.0
618 | 135.0 | 135.0 | 135.0 | 135.0
659 | 131.0 | 135.0 | 135.0 | 135.0
701 | 104.1 | 134.3 | 135.0 | 135.0
743 | 56.5 | 134.5 | 118.7 | 135.0
785 | 0.0 | 135.0 | 67.5 | 135.0
828 | 0.0 | 135.0 | 65.4 | 137.5
871 | 0.0 | 135.0 | 62.2 | 139.0
914 | 0.0 | 135.0 | 57.2 | 139.7
957 | 4.4 | 135.0 | 47.6 | 141.7
1002 | 13.9 | 125.3 | 37.5 | 157.8
1047 | 23.0 | 71.1 | 29.5 | 188.7
1093 | 43.9 | 21.9 | 19.2 | 217.7
1137 | 75.7 | 5.0 | 0.5 | 217.2
1180 | 117.8 | 0.0 | 0.0 | 175.0
1224 | 151.0 | 0.0 | 0.0 | 127.9
1267 | 186.0 | 0.0 | 0.0 | 64.3
1309 | 217.6 | 21.9 | 14.2 | 27.6
1351 | 229.9 | 57.2 | 25.8 | 3.9
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

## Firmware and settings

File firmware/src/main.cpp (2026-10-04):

#include <Arduino.h>
#include <WiFi.h>
#include <LittleFS.h>

#include "Config.h"
#include "IMotionSink.h"
#include "IRelaySink.h"
#include "ServoPair.h"
#include "RelayController.h"
#include "SettingsStore.h"
#include "SequenceStore.h"
#include "PlaybackEngine.h"
#include "WebApi.h"
#include "NetworkLink.h"
#include "NetworkMotionSink.h"
#include "SerialBridge.h"

ServoPair servos;
RelayController relay;
SettingsStore settingsStore;
SequenceStore sequenceStore;
PlaybackEngine playback;
WebApi webApi;
NetworkLink networkLink;
NetworkMotionSink networkMotionSink;
SerialBridge serialBridge;

static const IPAddress AP_IP(192, 168, 4, 1);
static const IPAddress AP_NETMASK(255, 255, 255, 0);

uint32_t lastTickMs = 0;
bool nodeMotorActive = false; // NODE only — see NODE_WIFI_TX_POWER_* in Config.h

// Role wiring (networkLink.begin/serialBridge.begin/sink selection below)
// only happens once here in setup(), matching the documented "network.*
// changes need a reboot" behavior. POST /api/settings can flip
// settingsStore's live networkMode in RAM immediately, well before any
// reboot — loop() must keep gating on this boot-time snapshot rather than
// re-reading live settings, or it starts calling serialBridge.loopTick()
// against a SerialBridge whose network_ pointer was never set (begin()
// never ran for the new role), crashing on the first PC command.
OperatingMode bootNetworkMode = OperatingMode::STANDALONE;

void setup() {
  Serial.begin(115200);
  delay(200);
  Serial.println();
  Serial.println("[SELFTEST] booting servo-motion-controller");
  Serial.printf("[SELFTEST] firmware version=%s\n", FIRMWARE_VERSION);

  settingsStore.load();
  const PersistedSettings &settings = settingsStore.settings();
  bootNetworkMode = settings.networkMode;
  Serial.printf("[SELFTEST] settings loaded (version=%u, autostart=%d)\n", settings.version,
                settings.autostartEnabled ? 1 : 0);

  servos.x().begin(SERVO_X_PIN, settings.servoX.minUs, settings.servoX.maxUs, settings.servoX.minAngle,
                   settings.servoX.maxAngle, settings.servoX.invert);
  servos.y().begin(SERVO_Y_PIN, settings.servoY.minUs, settings.servoY.maxUs, settings.servoY.minAngle,
                   settings.servoY.maxAngle, settings.servoY.invert);
  servos.writeAngles(settings.servoX.centerAngle, settings.servoY.centerAngle);
  Serial.printf("[SELFTEST] servos attached X=pin%d %u-%uus, Y=pin%d %u-%uus\n", SERVO_X_PIN,
                settings.servoX.minUs, settings.servoX.maxUs, SERVO_Y_PIN, settings.servoY.minUs,
                settings.servoY.maxUs);

  relay.begin(RELAY_PIN, settings.relayActiveLow);
  Serial.printf("[SELFTEST] relay pin=%d active_%s, starting off\n", RELAY_PIN,
                settings.relayActiveLow ? "low" : "high");

  bool fsOk = LittleFS.begin(true);
  Serial.printf("[SELFTEST] littlefs mount %s\n", fsOk ? "OK" : "FAILED");

  sequenceStore.begin();
  SequenceInfo seqInfos[SEQ_MAX_LISTED];
  uint8_t seqCount = sequenceStore.listSequences(seqInfos, SEQ_MAX_LISTED);
  Serial.printf("[SELFTEST] sequences stored: %u\n", seqCount);

  // Keeps the WiFi driver's own AP config (SSID/password/etc, a separate
  // blob from this project's own "app" NVS namespace) purely in RAM instead
  // of also writing it to flash on every WiFi.softAP() call. Without this, a
  // stale copy from a *previous* boot's config can end up fought over with
  // what's explicitly set below right after — a documented arduino-esp32
  // gotcha, and confirmed live on this project's own ESP32-S3 hardware: a
  // correct password was rejected with wpa_supplicant reporting WRONG_KEY
  // even right after a full chip erase.
  WiFi.persistent(false);

  // softAP() must run before softAPConfig() — the reverse order is a known
  // arduino-esp32 footgun where the AP's security (the password) silently
  // doesn't take, even though softAP() itself reports success and the
  // network still shows as WPA2 in a scan. See README.md's "Access point"
  // section.
  WiFi.mode(WIFI_AP);
  const bool hasPassword = strlen(settings.apPassword) >= 8;
  const bool apOk = hasPassword ? WiFi.softAP(settings.apSsid, settings.apPassword, AP_WIFI_CHANNEL)
                                 : WiFi.softAP(settings.apSsid, nullptr, AP_WIFI_CHANNEL);
  WiFi.softAPConfig(AP_IP, AP_IP, AP_NETMASK);
  Serial.printf("[SELFTEST] wifi AP %s ssid=%s ip=%s\n", apOk ? "up" : "FAILED", settings.apSsid,
                WiFi.softAPIP().toString().c_str());

  networkLink.begin(settings.networkMode, settings.nodeId);

  // MASTER drives selected Node(s) over ESP-NOW instead of a local servo, so
  // PlaybackEngine's jog/pattern/sequence logic is repointed at a
  // NetworkAngleSink; every other mode drives the physical ServoController
  // exactly as in v1. Autostart only makes sense with a real attached servo.
  IMotionSink *sink = &servos;
  IRelaySink *relaySink = &relay;
  if (settings.networkMode == OperatingMode::MASTER) {
    // Always full power — see WIFI_TX_POWER_MAX's comment in Config.h. Set
    // explicitly rather than just never lowering it, so this doesn't
    // silently depend on the core's own boot-time default matching.
    WiFi.setTxPower(static_cast<wifi_power_t>(WIFI_TX_POWER_MAX));
    networkMotionSink.begin(&networkLink);
    sink = &networkMotionSink;
    // A Master's own D7 stays idle: its light toggle drives the selected
    // Node(s)' relays over ESP-NOW, exactly like its trackpad does.
    relaySink = &networkMotionSink;
    serialBridge.begin(&networkLink);
    networkLink.onSeqAck([](uint8_t nodeId, const char *name, SeqAckStatus status, uint16_t points) {
      serialBridge.reportUploadResult(nodeId, name, status, points);
    });
    networkLink.onSpaceReply([](uint8_t nodeId, uint32_t freeBytes) {
      serialBridge.reportSpaceReply(nodeId, freeBytes);
    });
    networkLink.onPlayAck([](uint8_t nodeId, const char *name, PlayAckStatus status) {
      serialBridge.reportPlayResult(nodeId, name, status);
      webApi.reportPlayResult(nodeId, name, status);
    });
    // A Node handed over to its own playback must stop receiving the Master's
    // live stream too — see NetworkLink::onHandover. Only when the Master's
    // current target selection actually reaches that Node, so playing on
    // Node 3 doesn't stop a pattern the Master is running on Node 5.
    networkLink.onHandover([](uint8_t targetNode) {
      if (networkMotionSink.drives(targetNode)) playback.releaseLiveControl();
    });
  } else if (settings.networkMode == OperatingMode::NODE) {
    networkLink.onNodeCommand([](float angleX, float angleY, bool relayOn) {
      playback.onNetworkCommand(angleX, angleY, relayOn, millis());
    });
    // A Master remotely uploading a sequence is just a remotely-triggered
    // recording: start/stop reuse the exact same PlaybackEngine/SequenceStore
    // calls the local /api/record/start|save routes make (see WebApi.cpp) —
    // the servo moves and the buffer fills via the ordinary RECORDING-mode
    // path in PlaybackEngine::tick(), since onNetworkCommand already leaves
    // RECORDING mode untouched.
    networkLink.onSeqStart([]() {
      // A Master resends SEQ_START several times for delivery robustness —
      // a lost one is otherwise invisible, since the servo still moves on
      // ordinary CMD packets regardless of recording state (see
      // onNetworkCommand above). Without this guard, a duplicate that's
      // merely delayed rather than lost — arriving after capture is
      // already under way — would silently reset the in-progress
      // recording back to empty. Once actually recording, further starts
      // are a no-op until the matching SEQ_STOP.
      if (playback.mode() != PlaybackMode::RECORDING) {
        sequenceStore.startRecording();
        playback.startRecording(millis());
      }
    });
    networkLink.onSeqStop([](const char *name) {
      playback.stopRecording();
      sequenceStore.stopRecording();
      // SaveResult and SeqAckStatus share the same numeric reason codes by
      // design (SequenceStore stays free of any NetworkLink/protocol
      // dependency) — see both enums' definitions.
      SaveResult result = sequenceStore.saveAs(name);
      networkLink.sendSeqAck(name, static_cast<SeqAckStatus>(result), sequenceStore.recordedPointCount());
    });
    networkLink.onSeqClear([]() { sequenceStore.clearAll(); });
    networkLink.onSpaceQuery([]() { networkLink.sendSpaceReply(SequenceStore::freeSpaceBytes()); });
    // Remote play/stop: the same calls the local /api/sequence/play|stop
    // routes make (see WebApi.cpp).
    networkLink.onSeqPlay([](const char *name) {
      // Loading reuses the recording buffer, so it would wipe a capture in
      // progress (e.g. an upload) — refuse instead.
      if (playback.mode() == PlaybackMode::RECORDING) {
        networkLink.sendPlayAck(name, PlayAckStatus::Busy);
        return;
      }
      // Already looping this one: a repeated request (PC tools send it more
      // than once for delivery robustness) must not restart it from zero.
      char safeName[SEQ_NAME_MAX_LEN + 1];
      if (playback.mode() == PlaybackMode::SEQUENCE &&
          SequenceStore::sanitizeName(name, safeName, sizeof(safeName)) &&
          strcmp(safeName, sequenceStore.activeName()) == 0) {
        networkLink.sendPlayAck(name, PlayAckStatus::Ok);
        return;
      }
      if (sequenceStore.loadNamed(name)) {
        playback.startSequencePlayback(millis());
        networkLink.sendPlayAck(name, PlayAckStatus::Ok);
      } else {
        // loadNamed() has already emptied the buffer, so don't leave a
        // previously playing sequence "playing" nothing.
        playback.stopSequencePlayback();
        networkLink.sendPlayAck(name, PlayAckStatus::UnknownSequence);
      }
    });
    networkLink.onSeqHalt([]() { playback.stopSequencePlayback(); });
  }
  playback.begin(sink, &sequenceStore, relaySink);
  playback.setAngleLimits(settings.servoX.minAngle, settings.servoX.maxAngle, settings.servoY.minAngle,
                          settings.servoY.maxAngle);

  if (settings.networkMode != OperatingMode::MASTER) {
    // Applied before the web server comes up: a configured pattern/sequence
    // is already looping with zero user interaction, surviving reset/power-cycle.
    playback.applyAutostart(settings, millis());
    if (settings.autostartEnabled) {
      Serial.printf("[SELFTEST] autostart engaged: mode=%d\n", static_cast<int>(playback.mode()));
    } else {
      Serial.println("[SELFTEST] autostart disabled");
    }
  }

  webApi.begin(&playback, &sequenceStore, &settingsStore, &servos, &relay, &networkLink, sink, AP_IP);
  Serial.println("[SELFTEST] webserver started, ws clients=0");

  Serial.printf("[SELFTEST] free heap=%u bytes, network mode=%d node_id=%u\n", ESP.getFreeHeap(),
                static_cast<int>(settings.networkMode), settings.nodeId);
}

void loop() {
  const uint32_t now = millis();

  if (now - lastTickMs >= TICK_INTERVAL_MS) {
    lastTickMs = now;
    playback.tick(now);
    networkLink.reportLocalAngles(servos.getX(), servos.getY());
    networkLink.reportLocalRelay(relay.relayState());

    if (bootNetworkMode == OperatingMode::NODE) {
      const bool motorActive = playback.mode() != PlaybackMode::IDLE;
      if (motorActive != nodeMotorActive) {
        nodeMotorActive = motorActive;
        WiFi.setTxPower(static_cast<wifi_power_t>(
            motorActive ? NODE_WIFI_TX_POWER_ACTIVE : WIFI_TX_POWER_MAX));
      }
    }
  }

  networkLink.loopTick(now);
  if (bootNetworkMode == OperatingMode::MASTER) {
    serialBridge.loopTick();
  }

  webApi.loopTick(now);
}

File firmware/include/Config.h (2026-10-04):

#pragma once

#include <stddef.h>
#include <stdint.h>

// arduino-esp32's default C++ standard doesn't reliably provide std::clamp,
// so use a small local helper instead of depending on <algorithm>/C++17.
template <typename T>
static inline T clampValue(T value, T lo, T hi) {
  return value < lo ? lo : (value > hi ? hi : value);
}

// ---- Servos (pan/tilt) ----
// A node drives a two-axis head: X (pan) on D10, Y (tilt) on D3.
//
// Both are picked by silkscreen pin rather than GPIO number, because the same
// label sits on a different GPIO per board: the XIAO ESP32S3's D10/D9 are
// swapped relative to the ESP32C3 (D10=GPIO9 on the S3 vs D10=GPIO10 on the
// C3). Selecting by GPIO number instead would move a servo signal to a
// different physical pin depending on which board is being built.
//
// D3 is GPIO5 on the C3 and GPIO4 on the S3 — neither is a strapping pin on
// its chip, and neither is used by anything else in this firmware.
//
// Both servos share LEDC timer 0: they run at the same 50Hz, which is exactly
// what a shared timer supports, and the C3 (the tighter of the two chips) has
// 6 LEDC channels for 2 servos. See ServoController::begin().
#if defined(ARDUINO_XIAO_ESP32S3)
static constexpr uint8_t SERVO_X_PIN = 9; // XIAO ESP32S3 D10 / GPIO9
static constexpr uint8_t SERVO_Y_PIN = 4; // XIAO ESP32S3 D3  / GPIO4
#else
static constexpr uint8_t SERVO_X_PIN = 10; // XIAO ESP32C3 D10 / GPIO10
static constexpr uint8_t SERVO_Y_PIN = 5;  // XIAO ESP32C3 D3  / GPIO5
#endif
static constexpr uint16_t SERVO_DEFAULT_MIN_US = 500;
static constexpr uint16_t SERVO_DEFAULT_MAX_US = 2500;
static constexpr float SERVO_DEFAULT_MIN_ANGLE = 0.0f;
static constexpr float SERVO_DEFAULT_MAX_ANGLE = 270.0f;
static constexpr float SERVO_DEFAULT_CENTER_ANGLE = 135.0f;

// ---- Relay (light switch) ----
// Same silkscreen pin (D7) on both boards but a different GPIO underneath,
// for the same reason SERVO_PIN above is selected per board rather than by
// GPIO number. D7 doubles as UART0's RX pin on both XIAOs; it's free to use
// as an ordinary output here because both board definitions build with
// ARDUINO_USB_CDC_ON_BOOT=1, so Serial — including the Master's PC bridge —
// runs over native USB and never touches UART0. See docs/wiring.md.
#if defined(ARDUINO_XIAO_ESP32S3)
static constexpr uint8_t RELAY_PIN = 44; // XIAO ESP32S3 D7 / GPIO44
#else
static constexpr uint8_t RELAY_PIN = 20; // XIAO ESP32C3 D7 / GPIO20
#endif
// Most opto-isolated relay boards close the contact when their IN pin is
// pulled *low*; bare transistor/MOSFET drivers are the other way around.
// Configurable in Settings so either wiring works without a reflash.
static constexpr bool RELAY_DEFAULT_ACTIVE_LOW = false;

// ---- RANDOM pattern ----
// Dwell between moves is drawn uniformly from [min, max]; each move itself is
// slew-limited to maxSpeed and eased in/out, so the servo is never asked for
// the instant step a naive "jump to a random angle" would produce. See
// PatternEngine::computeRandomAngle().
static constexpr uint32_t PATTERN_RANDOM_DEFAULT_MIN_INTERVAL_MS = 1500;
static constexpr uint32_t PATTERN_RANDOM_DEFAULT_MAX_INTERVAL_MS = 6000;
static constexpr float PATTERN_RANDOM_DEFAULT_MAX_SPEED_DPS = 90.0f;
static constexpr float PATTERN_RANDOM_MIN_SPEED_DPS = 5.0f;
// A 270-degree hobby servo's own no-load speed is roughly 300-600 deg/s, so
// anything above this is asking for more than the gear train can deliver —
// the servo would just saturate and the motion stops being predictable.
static constexpr float PATTERN_RANDOM_MAX_SPEED_DPS = 400.0f;
static constexpr uint32_t PATTERN_RANDOM_MIN_MOVE_MS = 150;  // floor for very short hops
static constexpr uint32_t PATTERN_RANDOM_MIN_SETTLE_MS = 100; // guaranteed hold after arriving

// ---- Timing ----
static constexpr uint32_t TICK_INTERVAL_MS = 20;    // 50 Hz playback tick
static constexpr uint32_t RECORD_INTERVAL_MS = 50;  // 20 Hz recording capture
static constexpr uint32_t STATUS_BROADCAST_MS = 100; // 10 Hz WS status push
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

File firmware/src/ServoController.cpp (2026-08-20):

#include "ServoController.h"
#include "Config.h"
#include <cmath>

void ServoController::begin(uint8_t pin, uint16_t minUs, uint16_t maxUs, float minAngle, float maxAngle,
                             bool invert) {
  pin_ = pin;
  minUs_ = minUs;
  maxUs_ = maxUs;
  minAngle_ = minAngle;
  maxAngle_ = maxAngle;
  invert_ = invert;

  // One LEDC timer serves both servos of a pan/tilt head: they share the same
  // 50Hz, which is exactly what a shared timer supports, and each still gets
  // its own LEDC channel (the C3 has 6). Allocated once rather than per
  // instance — calling it again per servo would be harmless today, but it's a
  // global side effect and doesn't belong in a per-object begin().
  static bool timerAllocated = false;
  if (!timerAllocated) {
    ESP32PWM::allocateTimer(0);
    timerAllocated = true;
  }
  servo_.setPeriodHertz(50);
  servo_.attach(pin_, minUs_, maxUs_);
  attached_ = true;

  currentAngle_ = (minAngle_ + maxAngle_) / 2.0f;
  writeAngle(currentAngle_);
}

void ServoController::writeAngle(float degrees) {
  if (!attached_) return;
  // clampValue() can't rescue a NaN (every comparison against NaN is false,
  // so it falls through unclamped) and casting a non-finite float to int
  // downstream is undefined behavior — reject it here and hold the last
  // known-good position rather than risk a garbage pulse width.
  if (!isfinite(degrees)) return;
  const float clamped = clampValue(degrees, minAngle_, maxAngle_);
  currentAngle_ = clamped;

  // ESP32Servo's write(int) clamps internally to 0-180 degrees and only treats
  // values >=500 as raw microseconds, so it cannot drive wide-range (e.g. 270°)
  // servos correctly. Map degrees -> pulse width ourselves and go straight to
  // writeMicroseconds() to support the full calibrated angle range.
  const float span = maxAngle_ - minAngle_;
  float t = span != 0.0f ? (clamped - minAngle_) / span : 0.0f;
  if (invert_) t = 1.0f - t;
  const int pulseUs = minUs_ + static_cast<int>(t * static_cast<float>(maxUs_ - minUs_));
  servo_.writeMicroseconds(pulseUs);
}

void ServoController::setCalibration(uint16_t minUs, uint16_t maxUs, float minAngle, float maxAngle) {
  minUs_ = minUs;
  maxUs_ = maxUs;
  minAngle_ = minAngle;
  maxAngle_ = maxAngle;
  if (attached_) {
    servo_.detach();
    servo_.attach(pin_, minUs_, maxUs_);
    writeAngle(currentAngle_);
  }
}

void ServoController::setInvert(bool invert) {
  invert_ = invert;
  if (attached_) writeAngle(currentAngle_);
}

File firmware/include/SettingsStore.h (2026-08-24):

#pragma once

#include <stdint.h>
#include <stddef.h>
#include "Config.h"
#include "PatternEngine.h"

enum class AutostartTarget : uint8_t {
  NONE = 0,
  PATTERN = 1,
  SEQUENCE = 2
};

// STANDALONE: today's behavior, no ESP-NOW. NODE: joins a Master's network,
// accepts wireless positioning commands in addition to local jog/pattern/
// sequence control. MASTER: bridges USB-serial commands from a PC to CMD
// broadcasts for NODEs; no local servo/playback role.
enum class OperatingMode : uint8_t {
  STANDALONE = 0,
  NODE = 1,
  MASTER = 2
};

// One servo axis's calibration, stored twice in PersistedSettings.
struct ServoCalibration {
  uint16_t minUs = SERVO_DEFAULT_MIN_US;
  uint16_t maxUs = SERVO_DEFAULT_MAX_US;
  float minAngle = SERVO_DEFAULT_MIN_ANGLE;
  float maxAngle = SERVO_DEFAULT_MAX_ANGLE;
  float centerAngle = SERVO_DEFAULT_CENTER_ANGLE;
  bool invert = false;
};

struct PersistedSettings {
  uint32_t magic = SETTINGS_MAGIC;
  uint16_t version = SETTINGS_VERSION;

  char apSsid[33] = {0};
  char apPassword[65] = {0};

  // One block per axis: X (pan, D10) and Y (tilt, D3) are usually different
  // servos with different mechanical ranges, so they calibrate separately.
  ServoCalibration servoX;
  ServoCalibration servoY;

  // Relay/light output on D7 — see RELAY_PIN in Config.h.
  bool relayActiveLow = RELAY_DEFAULT_ACTIVE_LOW;

  bool autostartEnabled = false;
  AutostartTarget autostartTarget = AutostartTarget::NONE;
  // One pattern per axis: the two run independently, so a head can (say) sweep
  // in X while holding a slow triangle in Y.
  PatternParams autostartPatternX;
  PatternParams autostartPatternY;
  char autostartSequenceName[24] = {0}; // which /seq/<name>.bin to loop, when target == SEQUENCE

  OperatingMode networkMode = OperatingMode::STANDALONE;
  uint8_t nodeId = NET_NODE_ID_MIN;
};

class SettingsStore {
public:
  // Loads from NVS, or writes+applies factory defaults if absent/corrupt/version-mismatched.
  void load();
  void save();
  void factoryDefaults();

  PersistedSettings &settings() { return settings_; }
  const PersistedSettings &settings() const { return settings_; }

private:
  PersistedSettings settings_;
  void generateDefaultSsid(char *out, size_t outLen);
  // Overlays settings_'s SSID/password/network mode/node id from their own
  // NVS key, or seeds that key from settings_'s current values if it doesn't
  // exist yet. See Config.h's NET_IDENTITY_NVS_KEY comment.
  void loadNetworkIdentity();
  void saveNetworkIdentity();
};

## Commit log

2026-07-28 initial version
    [Seeed Studio XIAO ESP32C3.stl, muizei-25kg-case-hack-for-seeedstudio-esp32c3.scad, muizei-25kg-case-hack-for-seeedstudio-esp32c3.stl]
2026-07-28 model update
    [muizei-25kg-case-hack-for-seeedstudio-esp32c3.scad, muizei-25kg-case-hack-for-seeedstudio-esp32c3.stl]
2026-07-28 new model
    [muizei-25kg-case-hack-for-seeedstudio-esp32c3.scad, muizei-25kg-case-hack-for-seeedstudio-esp32c3.stl]
2026-07-28 update model
    [muizei-25kg-case-hack-for-seeedstudio-esp32c3.scad, muizei-25kg-case-hack-for-seeedstudio-esp32c3.stl]
2026-07-29 gamepad-controller tool
    [muizei-25kg-case-hack-for-seeedstudio-esp32c3.scad, muizei-25kg-case-hack-for-seeedstudio-esp32c3.stl]
2026-07-29 improve multimaster
    [tecording-test-1.csv, test-holder.scad, test-holder.stl]
2026-07-29 test recordings
    [tecording-test-1.csv]
2026-08-10 multicontroller mapping
    [test-holder-stand.stl, test-holder.scad]
2026-08-10 upload recordings to nodes
    [4.csv, rec.csv]
2026-08-11 fix restart on upload
    [NetworkLink.cpp, NetworkLink.h, main.cpp]
2026-08-11 wifi power reduced for motor nodes
2026-08-20 add relay control and random patterns
2026-08-20 2d servos
2026-08-21 recording test with controller
    [2d-rec.csv]
2026-08-24 fix WiFi AP password rejection and settings wiped on every reflash
    [joystick_master_gui.py]
2026-09-01 update docs and screenshots for two servos plus relay
    Screenshots still showed the single-servo UI (jog slider, one Angle
    column). Re-captured all of them against the current build:
    - web UI: firmware/data/ driven in headless Chromium against a mock
    backend returning WebApi.cpp's JSON shapes and /ws status stream
    - new webui-record-saved-plot.png: a saved recording plotted with its
    playhead, alongside the live two-axis + light trace
    - PC GUIs: launched for real against a stand-in Master on a pty
    speaking the serial protocol; joystick controllers stubbed at the
    pygame.joystick boundary
    Docs corrected to match the firmware:
    - SERVO_PIN -> SERVO_X_PIN / SERVO_Y_PIN, two-servo power b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
    [WebApi.cpp, app.js, joystick_master_gui.py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]
2026-10-04 Play saved sequences on Nodes from every Master GUI
    The Master's web UI, master_gui.py and joystick_master_gui.py can now make
    Node(s) loop a sequence saved on their own flash, and stop it again.
    - Web UI: "Play Sequence on Nodes" card on the Master's Manual tab, acting
    on the Target selection. New routes POST /api/network/play {node,name}
    and /api/network/stop {node}; Node replies are pushed to the browser as
    a WebSocket play_result frame.
    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
